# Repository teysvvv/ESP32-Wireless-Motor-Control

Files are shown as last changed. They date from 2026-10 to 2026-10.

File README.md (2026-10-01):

# ESP32-Wireless-Motor-Control
# Project Overview
This project involves developing a wireless control and power supply system for a manual slope-climbing robot designed to travel from one edge of an inclined surface to the other. 

The system uses two **ESP32-DevKitC-32UE**. The first ESP32 is connected to a Funduino joystick shield, which collects user inputs and transmits them wirelessly through ESP-NOW. The second ESP32, mounted on the robot, receives these commands and communicates with the motor controllers through CAN using an MCP2515 module.

The robot is powered by a **4S battery**. To provide a regulated power supply for the ESP32, I designed a custom PCB incorporating two voltage regulation stages:

- **LM2596S-5:** Steps down the battery voltage to a regulated 5 V.
- **AMS1117-3.3:** Further regulates the 5 V supply to a stable 3.3 V for the ESP32.

## System Architecture

1. **Transmitter:** The first ESP32 reads joystick and button inputs through the Funduino joystick shield.
2. **Wireless Communication:** ESP-NOW transmits control data between the two ESP32 boards.
3. **Receiver:** The second ESP32 receives the commands and communicates with the motor controllers through the MCP2515 CAN module.
4. **Motor Control:**
   - Motor 1: Speed control with encoder feedback and position holding.
   - Motor 2: Steering position control.

## Software and Tools

- C++ / Arduino IDE
- ESP-NOW
- CAN communication
- KiCad

## Project Status

Under development and hardware testing.

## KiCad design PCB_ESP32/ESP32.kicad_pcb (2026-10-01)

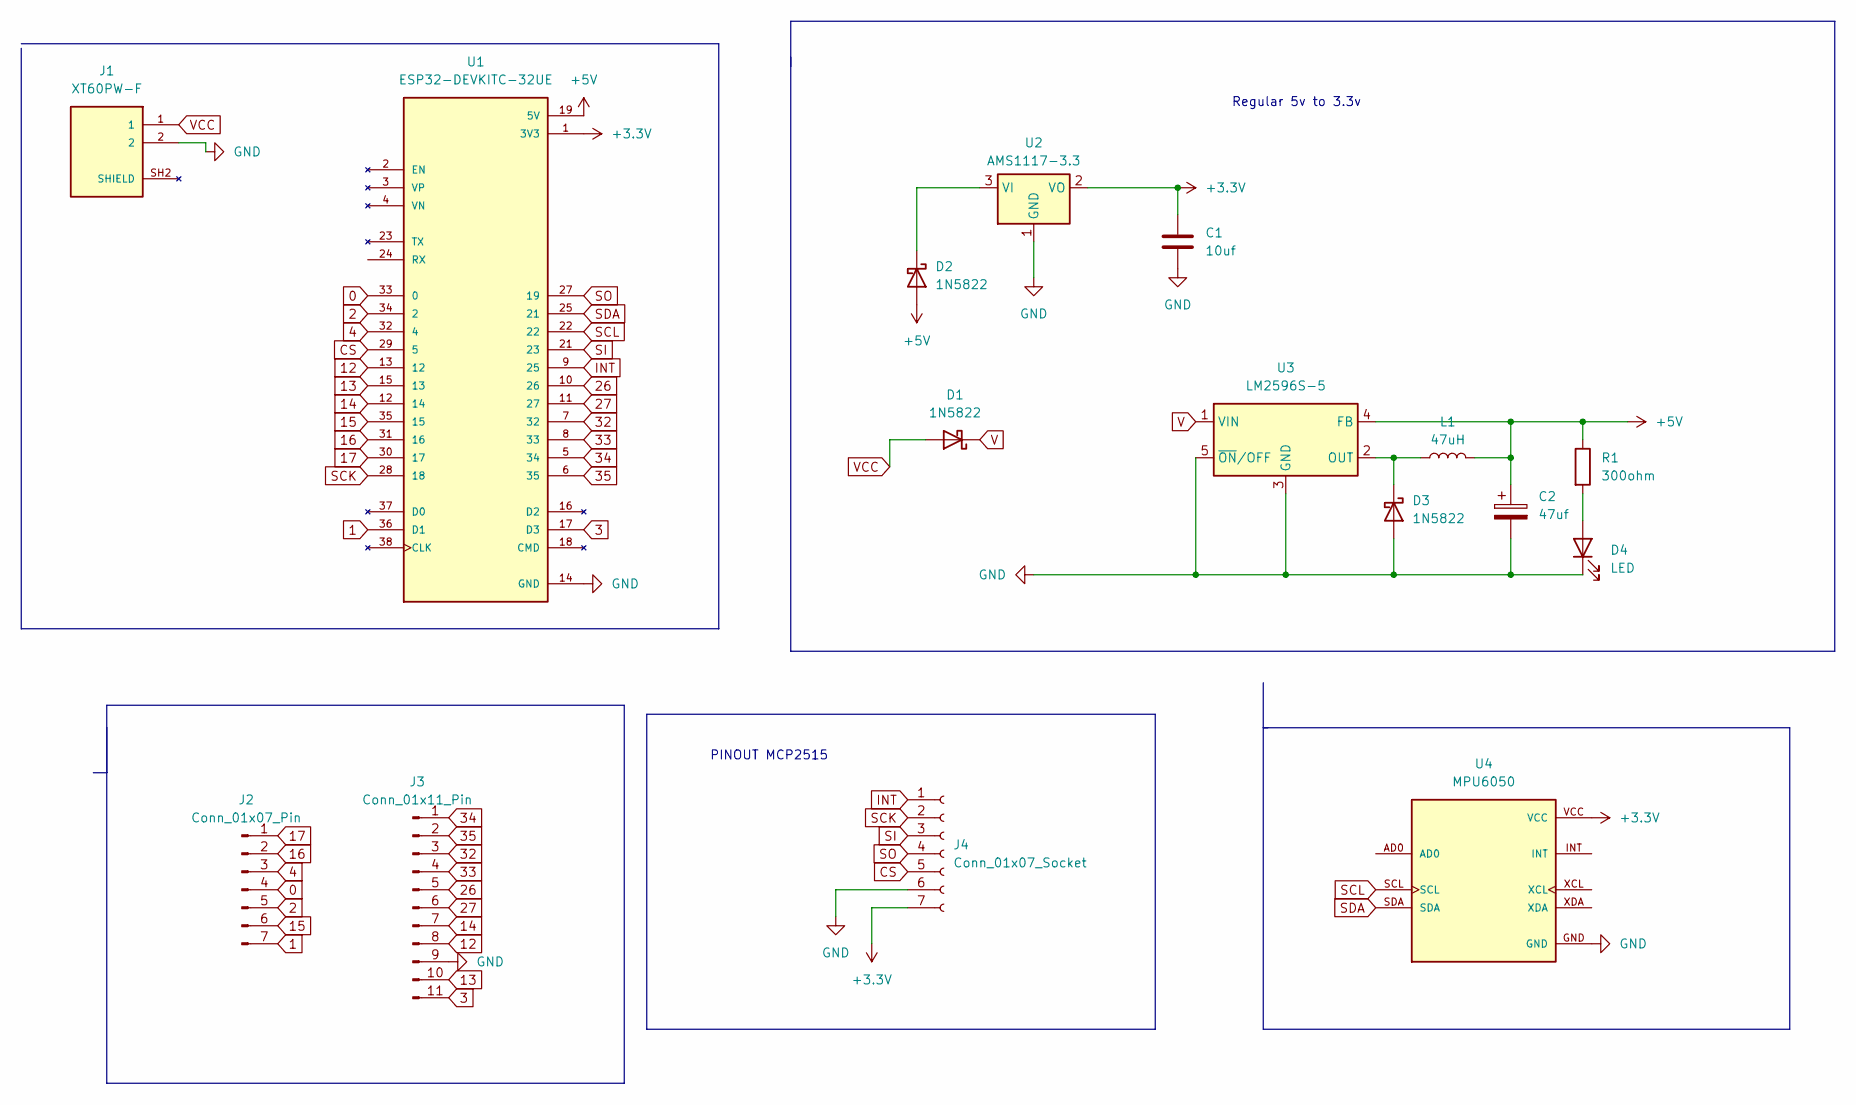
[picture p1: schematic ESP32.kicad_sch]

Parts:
C1: 10uf; C_0603_1608Metric
C2: 47uf; CP_Radial_D6.3mm_P2.50mm
D1, D2, D3: 1N5822; D_SMA
D4: LED; LED_D5.0mm
J1: XT60PW-F; AMASS_XT60PW-F; PARTREV 1.2
J2: Conn_01x07_Pin; PinHeader_1x07_P2.00mm_Vertical
J3: Conn_01x11_Pin; PinHeader_1x11_P2.54mm_Vertical
J4: Conn_01x07_Socket; PinSocket_1x07_P2.54mm_Vertical
L1: 47uH; L_Wuerth_HCI-7030
R1: 300ohm; R_0603_1608Metric
U1: ESP32-DEVKITC-32UE; ESPRESSIF_ESP32-DEVKITC-32UE; PARTREV V4
U2: AMS1117-3.3; SOT-223-3_TabPin2
U3: LM2596S-5; TO-263-5_TabPin3
U4: MPU6050; MODULE_OC09600; PARTREV NA

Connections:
0: J2.4, U1.33 (0)
1: J2.7, U1.36 (D1)
2: J2.5, U1.34 (2)
3: J3.11, U1.17 (D3)
4: J2.3, U1.32 (4)
12: J3.8, U1.13 (12)
13: J3.10, U1.15 (13)
14: J3.7, U1.12 (14)
15: J2.6, U1.35 (15)
16: J2.2, U1.31 (16)
17: J2.1, U1.30 (17)
26: J3.5, U1.10 (26)
27: J3.6, U1.11 (27)
32: J3.3, U1.7 (32)
33: J3.4, U1.8 (33)
34: J3.1, U1.5 (34)
35: J3.2, U1.6 (35)
+3.3V: C1.1, J4.7, U1.1 (3V3), U2.2 (VO), U4.VCC
+5V: C2.1, D2.2 (A), L1.2, R1.1, U1.19 (5V), U3.4 (FB)
CS: J4.5, U1.29 (5)
GND: C1.2, C2.2, D3.2 (A), D4.1 (K), J1.2, J3.9, J4.6, U1.14 (GND), U1.20 (GND), U1.26 (GND), U2.1 (GND), U3.3 (GND), U3.5 (~ON/OFF), U4.GND
INT: J4.1, U1.9 (25)
unnamed: D2.1 (K), U2.3 (VI)
unnamed: D4.2 (A), R1.2
SCK: J4.2, U1.28 (18)
SCL: U1.22, U4.SCL
SDA: U1.25 (21), U4.SDA
SI: J4.3, U1.21 (23)
SO: J4.4, U1.27 (19)
VCC: D1.2 (A), J1.1

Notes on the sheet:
PINOUT MCP2515
Regular 5v to 3.3v

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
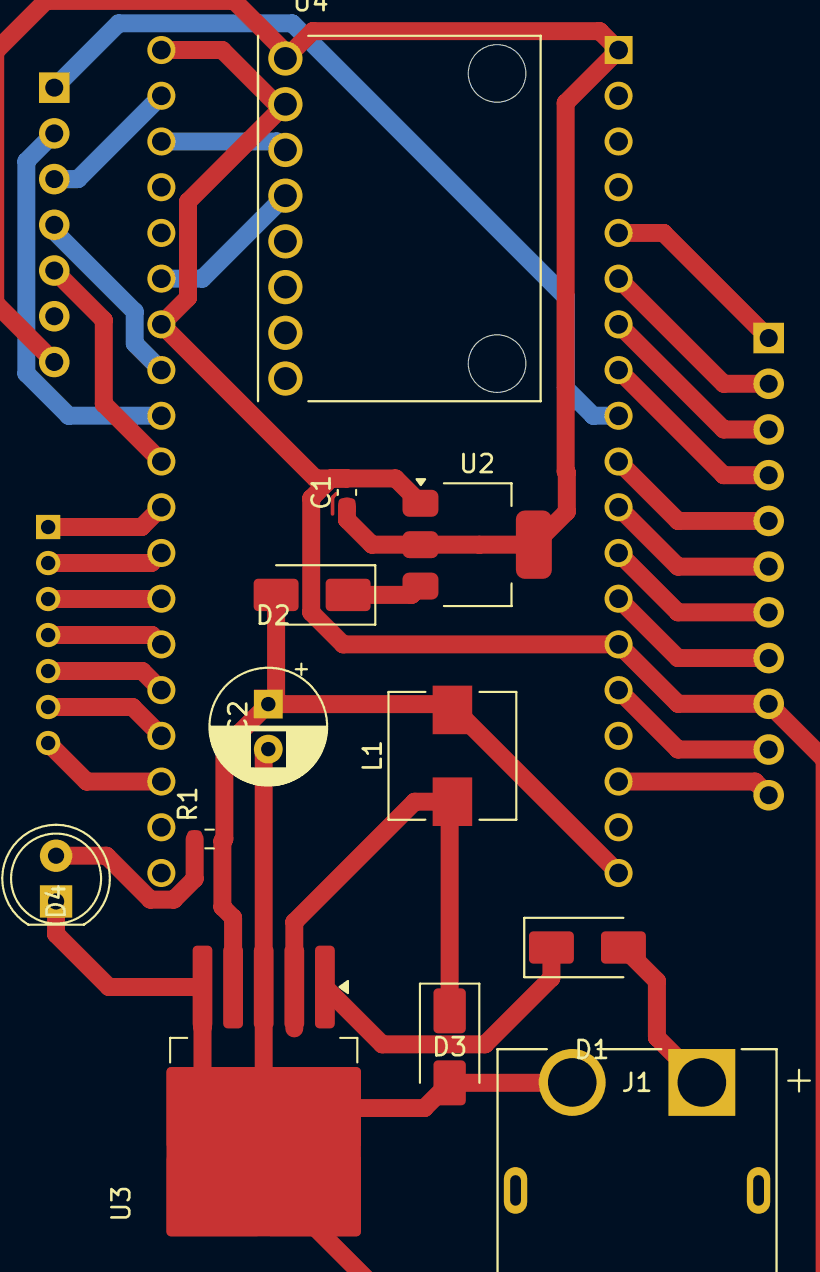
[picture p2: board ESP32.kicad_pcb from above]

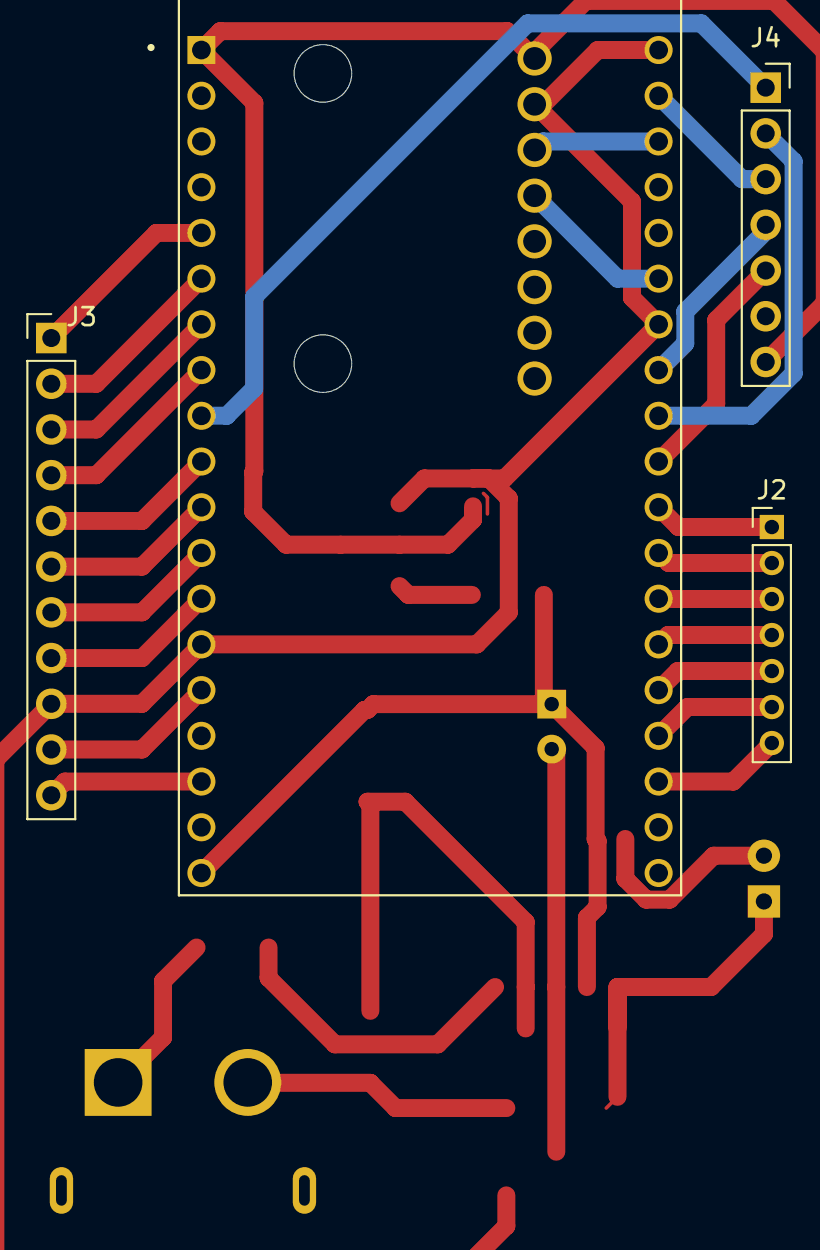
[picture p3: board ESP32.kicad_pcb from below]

Board: 2 copper layers, 16 parts (4 on the bottom side), 31 nets.

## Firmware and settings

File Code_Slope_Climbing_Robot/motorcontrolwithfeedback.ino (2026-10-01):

#include <SPI.h>
#include <mcp2515.h>
#include <SmartDriver.h>
#include <WiFi.h>
#include <esp_now.h>

// CAN
MCP2515 mcp2515(5);

struct can_frame can_msg_transmit;
struct can_frame can_msg_receive;

uint8_t commandData[8];

SmartDriver motor1; // MOTOR 1 = DRIVE
SmartDriver motor2;// MOTOR 2 = STEERING

// Encoder / SmartDriver feedback
float motor1_feedback_speed = 0.0;
float motor1_feedback_position = 0.0;
float holdPosition = 0.0;
bool holding = false;
const int DEADZONE = 20;

float motor2_feedback_position = 0.0;

// Data received from ESP1
typedef struct {
  int yVal;
  int btnA;
  int btnB;
  int btnC;
  int btnD;
} ControlData;

ControlData controls;

// Desired commands
float driveSpeed = 0.0;
float steerPosition = 0.0;
unsigned long lastSteerTime = 0;
const unsigned long STEER_INTERVAL = 100;
const int CENTER_Y = 453;

//esp recieving
void OnDataRecv(const esp_now_recv_info_t *info, const uint8_t *incomingData, int len) {
  if (len == sizeof(ControlData)) {

    // Copy the received ESP1 data into "controls"
    memcpy(&controls, incomingData, sizeof(controls));
  }
                }
void setup() {
  Serial.begin(115200);

  delay(1000);
  mcp2515.reset();
  mcp2515.setBitrate(
    CAN_1000KBPS,
    MCP_8MHZ
  );
  mcp2515.setNormalMode();
  WiFi.mode(WIFI_STA);

  delay(500);

  Serial.print("ESP2 MAC: ");
  Serial.println(WiFi.macAddress());
  if (esp_now_init() != ESP_OK) {
    Serial.println("ESP-NOW ERROR");
   return;
  }
  esp_now_register_recv_cb(
    OnDataRecv
  );
  Serial.println("ESP2 READY");
  
  // void setup for recieving message from smart driver
  mcp2515.reset();
  mcp2515.setBitrate(CAN_1000KBPS, MCP_8MHZ);
  mcp2515.setNormalMode();
}

void loop() {
 //motor1 
if (abs(controls.yVal - CENTER_Y) <= DEADZONE) {  //motor 1 holding position
  if (!holding) { 
    holdPosition = motor1_feedback_position; 
    holding = true; 
  } 
  motor1.positionMode = true; 
  motor1.speedMode = false;
  motor1.voltageMode = false; 
  motor1.goal = holdPosition; 
} else { //motor 1 moving
  holding = false; 
  motor1.positionMode = false; 
  motor1.speedMode = true; 
  motor1.voltageMode = false; 
  driveSpeed = map(controls.yVal, 0, 905, -5, 5); 
  motor1.goal = driveSpeed; 
} 
motor1.stop = false; 
motor1.reset = false;
motor1.getCommand(commandData); 

can_msg_transmit.can_id = 0x01; 
can_msg_transmit.can_dlc = 8; 

memcpy( 
  can_msg_transmit.data, 
  commandData, 
  8 
); 

mcp2515.sendMessage(&can_msg_transmit);

// MOTOR 2
if (millis() - lastSteerTime >= STEER_INTERVAL) {
  if (controls.btnA == 1) {
  steerPosition += 2.5;
}
else if (controls.btnB == 1) {
  steerPosition += 10.0;
}
else if (controls.btnC == 1) {
  steerPosition -= 2.5;
}
else if (controls.btnD == 1) {
  steerPosition -= 10.0;
}
  steerPosition = constrain(steerPosition, -270.0, 270.0);
  lastSteerTime = millis();

  motor2.positionMode = true;
  motor2.stop = false;
  motor2.reset = false;
  motor2.voltageMode = false;
  motor2.speedMode = false;
  motor2.goal = steerPosition * PI / 180.0;

  motor2.getCommand(commandData);

  can_msg_transmit.can_id = 0x02;
  can_msg_transmit.can_dlc = 8;

  memcpy(
    can_msg_transmit.data,
    commandData,
    8
  );
  mcp2515.sendMessage(&can_msg_transmit);
}
  delay(10);
  
  // void loop recieving message
  if (mcp2515.readMessage(&can_msg_receive) == MCP2515::ERROR_OK) {  
      if (can_msg_receive.can_id == 102){
        memcpy(&motor2_feedback_position, can_msg_receive.data, sizeof(float));
      }
      else if (can_msg_receive.can_id == 101) {
        memcpy(&motor1_feedback_position, can_msg_receive.data, sizeof(float));

        memcpy(&motor1_feedback_speed, can_msg_receive.data + 4, sizeof(float));
      }   
}
Serial.print("Drive target: ");
Serial.print(driveSpeed);

Serial.print(" | Actual speed: ");
Serial.print(motor1_feedback_speed);

Serial.print(" | Steering target: ");
Serial.print(steerPosition);
Serial.print(" deg");

Serial.print(" | Actual position: ");
Serial.println(motor2_feedback_position);
}

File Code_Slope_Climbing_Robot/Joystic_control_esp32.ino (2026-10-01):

#include <WiFi.h>
#include <esp_now.h>
uint8_t receiverAddress[] = {0xFC, 0xE8, 0xC0, 0xC3, 0x54, 0x94}; 
#define JOY_Y      35
#define BTN_A      32 
#define BTN_C      25 
#define BTN_D      26 
#define BTN_B      33 

typedef struct { int yVal; int btnA; int btnB; int btnC; int btnD; } ControlData;

ControlData controls;

void OnDataSent(const wifi_tx_info_t *info, esp_now_send_status_t status) {
  if (status != ESP_NOW_SEND_SUCCESS) {
    Serial.println("WARNING: ESP-NOW DELIVERY FAILED!");
  }
}

void setup() {
  Serial.begin(115200);

  delay(1000);
  pinMode(BTN_A, INPUT_PULLUP);
  pinMode(BTN_C, INPUT_PULLUP);
  pinMode(BTN_D, INPUT_PULLUP);
  pinMode(BTN_B, INPUT_PULLUP);

  
  WiFi.mode(WIFI_STA);
  delay(500);
  // Start ESP-NOW
  if (esp_now_init() != ESP_OK) {
    Serial.println("ERROR: ESP-NOW initialization failed!");
    return;
  }
  // Register send callback
  esp_now_register_send_cb(OnDataSent);

  // Add ESP32 #2 as peer
  esp_now_peer_info_t peerInfo = {};
  memcpy(peerInfo.peer_addr, receiverAddress, 6);
  peerInfo.channel = 0;
  peerInfo.encrypt = false;
  if (esp_now_add_peer(&peerInfo) != ESP_OK) {
    Serial.println("ERROR: Failed to add ESP32 #2!");
    return;
  }
  Serial.println();
  Serial.println("ESP32 #1 JOYSTICK TRANSMITTER");
  Serial.println("READY!");
}

void loop() {
  int rawY = analogRead(JOY_Y);
  controls.yVal = map( rawY, 0, 4095, 0, 1023 );
  typedef struct { int yVal; int btnA; int btnB; int btnC; int btnD; } ControlData;
  controls.btnA = !digitalRead(BTN_A);
  controls.btnC = !digitalRead(BTN_C);
  controls.btnD = !digitalRead(BTN_D);
  controls.btnB = !digitalRead(BTN_B);
  
  esp_err_t result = esp_now_send( receiverAddress, (uint8_t *)&controls, sizeof(controls) );
  
  Serial.print("Y: "); Serial.print(controls.yVal);
  Serial.print(" | A: "); Serial.print(controls.btnA);
  Serial.print(" | B: "); Serial.print(controls.btnB);
  Serial.print(" | C: "); Serial.print(controls.btnC);
  Serial.print(" | D: "); Serial.print(controls.btnD);
  if (result == ESP_OK) {
    Serial.println(" | SENT");
  
  } else {
    Serial.println(" | SEND ERROR");
  }
}
